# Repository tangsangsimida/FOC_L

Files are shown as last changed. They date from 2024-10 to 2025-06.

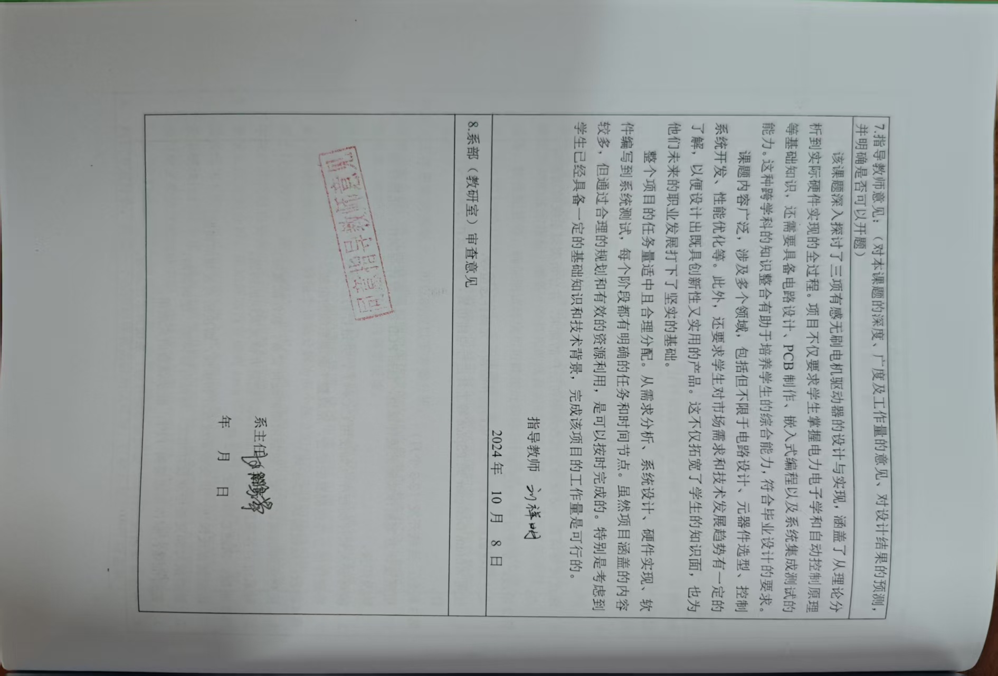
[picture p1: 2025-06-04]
paper/2203080517-汤红辉-智慧健康学院-三项有感无刷电机驱动器硬件设计/开题报告.jpg

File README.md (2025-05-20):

**目录结构概述**:  
该路径包含 6 个目录和 9 个文件，主要涉及 FOC（Field-Oriented Control，磁场定向控制）算法相关的项目、课程资料、代码库和文档。

---

### 目录结构详情

#### 目录 (6 个)
1. **参考项目**: 包含与 FOC 相关的参考项目或示例代码。
2. **CawFOC**: 一个 FOC 算法的实现项目或代码库。
3. **DengFOC**: 一个 FOC 算法的实现项目或代码库。
4. **odriver**: 与电机驱动相关的项目或工具。
5. **ts_foc_fw**: 与 FOC 固件（Firmware）相关的项目。
6. **Tsfoc_Soft_V0_1**: 一个 FOC 软件的早期版本（V0.1）。

#### 文件 (9 个)
1. **【手把手教学FOC算法】 课程例程包.zip**: 包含 FOC 算法的教学课程和示例代码的压缩包。
2. **bldc-master.zip**: 与 BLDC（无刷直流电机）相关的代码库或项目压缩包。
3. **eg2133_34对比.md**: 关于 eg2133 和 eg2134 芯片对比的 Markdown 文档。
4. **gitpush.sh**: 用于自动化 Git 推送操作的 Shell 脚本。
5. **LICENSE**: 项目的许可证文件，说明代码的使用权限和限制。
6. **README.md**: 项目的说明文档，包含项目简介、使用方法等信息。
7. **SCH_G431永磁双驱_2024-10-08.json**: 与永磁双驱电机相关的原理图设计文件（JSON 格式）。
8. **simple_focproject.zip**: 包含一个简单的 FOC 项目的压缩包。
9. **tree.txt**: 当前文件，记录了目录结构的树形图。

---

### 备注
- 该路径内容围绕 FOC 算法及其相关应用，包括电机控制、固件开发、课程资料等。
- 文件类型包括压缩包（`.zip`）、Markdown 文档（`.md`）、Shell 脚本（`.sh`）、JSON 文件等，表明项目内容多样化。

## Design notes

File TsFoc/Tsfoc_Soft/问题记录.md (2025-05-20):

# FOC开发过程中所遇到的关于软件和硬件上的坑

## 软件：

1. 结构体指针中包含结构体指针在申请内存的时候需要分别将所有结构体指针以及所包含的所有指针分别申请内存
2. stm32单片机的堆栈大小是通过cubeMX生成的时候自定义的，大量的结构体指针可能会导致堆区空间不足导致内存申请失败

## 硬件

1. 径向磁铁安装必须与编码器芯片对正，否则会出现精度丢失的情况，非常严重

# 当前为解决问题列表:

1. 低速正常，速度快一点之后就开始抖动，再快就死机了

   可能造成原因:

   角度传感器是模拟IIC速率可能不够

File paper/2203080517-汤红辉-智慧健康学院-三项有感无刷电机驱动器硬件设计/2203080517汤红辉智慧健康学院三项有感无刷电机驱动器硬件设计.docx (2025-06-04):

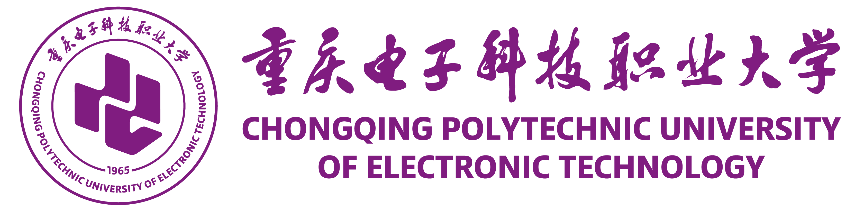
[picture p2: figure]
校徽与横式中英文标准字左右居中组合－重电紫（电子屏幕使用版）(1)

全日制学生毕业设计

任务书

学 院 智慧健康学院

专业班级 嵌入式技术应用

学生姓名 汤红辉 学号 2203080517

指导教师 刘祥明 王玺伟 职称 讲师 工程师

题 目 三项有感无刷电机驱动器硬件设计

2024年6月28日

毕业设计任务：

设计内容：1．掌握相关理论基础,深入学习和理解三项有感无刷电机（BLDC）的工作原理、控制策略及其应用场景。2．进行电机驱动电路的设计，包括但不限于功率电子元件的选择、电路拓扑结构的确定等。使用专业软件（如Altium Designer, PSpice等）进行电路仿真以验证设计的有效性。3. 基于设计方案制作实际的硬件原型，包括PCB板的设计与制作、元器件的焊接及调试。4.将硬件部分与控制算法结合，完成整个驱动系统的组装，并进行功能性和性能测试，确保其满足预期的技术指标。

设计指标：确保驱动器能够稳定驱动三项有感无刷电机，达到预定的速度和扭矩输出。实现对电机状态的实时监控与反馈调节，保证运行的安全性和稳定性。完成一套完整的硬件设计方案，包括电路图、PCB设计文件以及相关的技术文档。提交一份详尽的毕业设计论文，清晰阐述设计思路、实施步骤、实验结果及其分析。

设计任务要求：

1．具备扎实的电力电子学、自动控制原理等相关专业知识。2．能够熟练使用电路设计软件进行电路设计和仿真。3. 具有一定的动手能力，能够独立完成硬件的制作与调试工作。4. 在指导教师的帮助下，解决设计过程中遇到的各种问题，按时完成各阶段的任务。

主要参考文献：

[1]  顾伟康.一体化无刷直流电机控制研究和实现[D].东南大学,2015.
[2]  黄龙亮,胡鹏飞,陈玉洁,等.基于ARM的无刷直流电机容错控制系统研究[J].自动化应用,2024,65(12):103-104+108.DOI:10.19769/j.zdhy.2024.12.033.
[3]  王飞.BLDC驱动电路设计及应用[D].西安电子科技大学,2017.
[4]  谭加尼.基于STM32的无刷直流电机控制器研制[D].武汉工程大学,2020.DOI:10.27727/d.cnki.gwhxc.2020.000290.
[5]  敬心灵.基于STM32的无刷直流电机矢量控制系统研究[D].常州大学,2022.DOI:10.27739/d.cnki.gjsgy.2022.000412.
[6]  马鸿德.BLDC电机控制器的研究与设计[D].中国海洋大学,2015.
[7]  王聪.基于STM32的无刷直流电机控制系统研究[J].微处理机,2022,43(02):11-15.
[8]  赵国清,武涵.基于STM32的无感无刷直流电机控制系统设计[J].自动化应用,2024,65(05):142-148+152.DOI:10.19769/j.zdhy.2024.05.042.
[9]  方思鹏.无刷直流电机高性能驱动电路的设计与实现[D].电子科技大学,2023.DOI:10.27005/d.cnki.gdzku.2023.003895.
[10]  张平稳.高速无刷直流电机控制系统硬件电路设计[J].自动化应用,2019,(09):44-45+48.DOI:10.19769/j.zdhy.2019.09.017.

进度计划：

2024年9月 16 日至2024年10月19日：进行相关文献查找和阅读，了解三项有感无刷电机的工作原理及其驱动器设计的基本概念，并完成开题报告及开题答辩。

2024年10月20日至2024年12月21日：深入学习电机控制理论、电路设计基础以及相关电子元件的选择。开始进行初步的硬件设计工作，包括电路图绘制和元件选型。

2024年12月22日至2025年2月21日：完成详细的硬件设计方案，包括PCB设计、元器件采购等。着手制作原型并进行初步测试，确保各部分功能正常。

2025年2月22日至2025年3月21日：进行全面的系统集成和测试，优化驱动器性能。撰写毕业设计论文初稿，并进行查重。

2025年3月22日至2025年4月24日：进一步完善毕业设计论文，根据实验结果调整和优化设计。

2025年4月25日至2025年5月8日：准备答辩材料，完成毕业设计答辩。

任务起止日期： 2024 年 10 月 19 日至 2025 年 5 月 8 日

指导教师签字：

全日制学生毕业设计

开题报告

题 目 三项有感无刷电机驱动器硬件设计

学 院 智慧健康学院

专业班级 嵌入式2202

学生姓名 汤红辉 学号 2203080517

指导教师 刘祥明 王玺伟 职称 高级实验师

2024年 10月 8日

毕业设计（论文）开题报告

1.课题目的及意义，国内外研究现状分析

目的：

本项目旨在设计并实现一个用于三项有感无刷电机的高效、可靠的驱动器硬件。通过这一设计，期望能够优化电机控制性能，提高能效比，并为工业应用提供一种新的解决方案。

意义：

1. 提升电机运行效率和可靠性。
2. 推动电机控制技术的发展，特别是在高效节能领域。
3. 应对现代工业中对高性能电机驱动器的需求，促进相关产业的技术升级。

国内研究现状：

在中国，随着工业自动化水平的不断提高和对能源效率的关注增加，对于高性能电机驱动系统的需求日益增长。三项有感无刷电机（BLDC）因其高效能、长寿命以及良好的控制性能，在众多领域得到了广泛应用，如家用电器、电动车、工业自动化等。然而，相较于国际先进水平，国内在三项有感无刷电机驱动器的设计与制造方面仍存在一定的差距。虽然国内已有不少企业在进行三项有感无刷电机及其驱动器的研发和生产，但在高端应用领域，如航空航天、精密机床等，其电机控制精度和稳定性仍有待提高。当前国内市场上的电机驱动产品主要集中在中低端市场，而高端市场的份额则被国外品牌占据。这表明国内企业需要进一步提升技术水平以满足更高质量标准的要求。近年来，中国政府出台了一系列鼓励创新和技术升级的政策措施，旨在推动包括电机驱动在内的制造业向更高附加值方向转型。这些政策为电机驱动技术的发展提供了有力的支持。

国外研究现状：

在国外，尤其是欧美发达国家和地区，三项有感无刷电机驱动器的研究和应用已经达到了较高的水平，并广泛应用于多个高科技领域。国外研究机构和企业在三项有感无刷电机驱动器的技术创新方面取得了显著进展。例如，采用先进的控制算法（如矢量控制、直接转矩控制等）提高了电机的运行效率和动态响应速度；利用新材料（如碳化硅SiC功率器件）提升了驱动器的工作频率和能量转换效率。在高端制造、新能源汽车、医疗器械等领域，三项有感无刷电机驱动器的应用非常普遍。这些应用场景要求极高的可靠性、精确度以及适应复杂环境的能力，国外的产品往往能够更好地满足这些需求。为了降低开发成本并加快产品上市时间，许多国外制造商倾向于采用标准化和模块化设计理念。这种方法不仅有助于提高产品的兼容性和可维护性，还能促进整个行业的健康发展。

综上所述，尽管国内外在三项有感无刷电机驱动器的研究和发展方面均取得了一定的成绩，但总体来看，国外在技术创新、高端应用以及标准化设计等方面仍然领先于国内。因此，如何吸收借鉴国外先进技术经验的同时结合本国实际情况进行自主创新，是未来中国电机驱动行业面临的重要课题。通过持续的技术研发投入和人才培养，有望缩小与国际先进水平之间的差距，并在全球竞争中占据一席之地。

2.本课题的任务、重点内容、实现途径

课题任务：

设计并实现一款三项有感无刷电机驱动器，满足特定应用场景下的性能要求。完成从理论分析到实际硬件实现的全过程，包括电路设计、PCB制作、元件选型及系统集成测试。

重点内容：

在设计与开电机驱动时，需要重点关注以下几个方面：

1. 需求分析：明确驱动器的功能需求、性能指标以及用户需求。
2. 系统设计：包括电路设计、元器件选择、PCB布局等。
3. 数据处理与控制算法：开发适合的控制策略，保证电机高效稳定运行。

实现途径：

1. 使用Altium Designer或PSpice等工具进行电路设计与仿真
2. 进行详细的硬件原型设计与制作，并通过实验验证其性能。

硬件系统测试：对系统进行全面的测试，包括功能测试、性能测试和安全测试等，确保系统的稳定性和安全性。

3.课题可行性分析

三项有感无刷电机驱动器硬件设计项目的技术可行性主要基于以下几个方面：

1. 现有的技术基础：当前，电力电子技术和自动控制理论已经非常成熟，为本项目的实施提供了坚实的技术支持。例如，矢量控制和直接转矩控制等先进的电机控制算法已经被广泛应用于无刷直流电机的驱动系统中。此外，现代微控制器（MCU）和数字信号处理器（DSP）的发展也为电机控制系统的实现提供了强大的计算能力和丰富的接口资源。
2. 软件工具的支持：Altium Designer、PSpice等电路设计和仿真软件能够有效地辅助进行电路设计与验证。这些工具不仅简化了设计流程，还提高了设计的准确性和可靠性。通过这些软件工具的应用，可以对电路设计进行详细的仿真测试，提前发现并解决潜在的问题。
3. 元器件的选择：随着半导体制造工艺的进步，功率MOSFET、IGBT等高效能电子元件的成本不断下降，性能不断提升，这为三项有感无刷电机驱动器的设计提供了更多选择。同时，市场上也出现了许多专门为电机控制设计的专用集成电路（ASIC），这些都极大地促进了电机驱动器的小型化、高效化发展。
4. 成本效益分析：虽然高性能的电机驱动器在研发初期可能需要较高的投入，但考虑到其长期运行中的节能效果以及维护成本的降低，整体经济效益显著。特别是对于工业自动化领域，高效的电机驱动系统不仅能提高生产效率，还能大幅减少能源消耗，从而带来可观的经济回报。
5. 市场需求潜力：随着全球范围内对节能减排要求的不断提高，市场对高效能电机驱动器的需求日益增长。尤其是在新能源汽车、智能家居等领域，三项有感无刷电机驱动器的应用前景广阔。因此，开发一款性能优异的产品具有广阔的市场空间和良好的商业价值。

4.完成本课题所需的工作条件（如工具书、计算机、实验、调研等）及解决办法

学生宿舍管理系统的设计与实现课题所需的工作条件包括以下几个方面：

1. 工具书和文献：需要查阅与电力电子、自动控制理论、三项有感无刷电机及其驱动技术相关的专业书籍和技术文档。获取最新的研究成果和技术进展，以保证设计方案的先进性和科学性。

解决办法：利用学校图书馆或在线数据库查找并借阅相关领域的权威书籍和学术论文。参考官方文档和技术手册，以及所选用元器件的技术说明书。加入相关的技术论坛和社区，以便及时获取行业动态，并与其他研究者交流心得。

2. 计算机及软件环境：需要一台或多台配置较高的计算机用于电路设计、仿真、PCB制作以及后续的数据处理和分析工作。

解决办法：根据项目需求，选择适合的计算机配置，确保其能够满足高性能计算的要求。可以考虑使用学校的实验室资源或者自购高性能计算机。下载并安装所需的软件工具，确保所有工具均为最新版本，以获得最佳的功能支持和技术支持。对于一些昂贵的专业软件，可以通过教育许可的方式获取免费或低成本的使用权，许多软件厂商为学生提供特别优惠。

3. 实验条件：需要在一个配备齐全的实验室环境中进行硬件原型的制作和测试。这包括焊接设备、测量仪器（如示波器、万用表等）、电源供应器等。准备足够的测试数据，包括电机参数、运行状态记录等，以验证系统的正确性和稳定性。

解决办法：与学校实验室管理部门协商，争取获得实验室资源的使用权，特别是那些专门用于电子电路设计和测试的实验室。构建详细的测试计划，准备充分的测试数据和场景，确保每一个功能模块都能得到全面而严格的测试。

4. 调研：需要对现有的三项有感无刷电机驱动系统进行深入调研，了解其功能特点、优缺点以及用户反馈。收集目标应用领域的需求信息，明确最终用户的实际需求，为系统设计提供依据。

解决办法：通过问卷调查、访谈等方式直接从潜在用户那里收集需求信息。同时，也可以参考已有的市场研究报告和技术白皮书。参加行业会议、研讨会或展会，了解最新的产品趋势和技术发展动态。这不仅有助于获取第一手资料，还能建立有价值的行业联系。分析竞争对手的产品，找出它们的优势和不足之处，从而为自己的设计提供改进方向。

5.工作思路及方案分析

为了确保《三项有感无刷电机驱动器硬件设计》项目的顺利进行，以下是详细的工作思路及各阶段的方案分析：

1. 需求分析:明确项目的目标，包括提高电机控制精度、增强系统稳定性、优化能效等。通过问卷调查、访谈等方式收集来自潜在用户或相关领域的反馈信息，了解他们的具体需求。针对不同用户群体（如研发人员、维护人员和最终用户）的需求进行分析。研究市场上现有的同类产品，分析其功能特点、优缺点以及用户反馈，为本项目提供参考。整理调研结果，形成详细的需求文档，涵盖功能需求、性能需求、安全需求等方面，并明确优先级。在初步设计完成后，制作一个简易原型，进行初步测试以验证基本功能是否满足需求。
2. 系统设计:定义系统的整体架构，包括硬件部分（电路拓扑结构、元器件选型）、软件部分（控制算法的选择）以及人机交互界面的设计，考虑到电机驱动器的安全性要求，需加入必要的保护机制，如过流保护、温度监控等。编写详细的系统设计文档，包括ER图、流程图、电路原理图、PCB布局图等，确保设计的每个细节都经过充分考虑。使用Altium Designer、PSpice等工具进行电路仿真，验证设计方案的可行性和有效性。对于复杂的控制系统，可以利用MATLAB/Simulink进行系统级仿真。
3. 系统实现：根据设计方案制作实际的硬件原型，包括PCB设计、元器件采购及焊接。确保所有元件的质量符合标准，并按照设计图纸精确组装。如果涉及到嵌入式软件开发，则需编写相应的控制程序，并进行调试。选择合适的编程语言和开发环境（如C/C++、Keil、IAR等）。将硬件和软件部分结合起来进行全面的系统集成测试，确保各模块能够协同工作，达到预期的功能和性能指标。采用模块化设计方法，提高代码复用性和可维护性。每个功能模块独立开发和测试，最后集成到整个系统中。利用Eclipse等集成开发环境（IDE）提供的调试工具，方便进行代码调试，快速定位并解决问题。
4. 测试：包括测试范围、方法和标准，编写全面的测试用例，覆盖所有功能点和边界条件。按照预定的测试计划执行单元测试、集成测试和系统测试，记录并修复发现的问题。基于测试结果，对系统进行必要的性能优化，确保其满足预期的技术指标。准备一个模拟的或真实的测试环境，包括所需的硬件设备、软件配置等，确保测试环境尽可能接近实际应用场景。利用自动化测试工具（如LabVIEW, TestStand）来加速测试过程，提高测试效率和准确性。通过故意引入故障（如电源波动、信号干扰），测试系统的鲁棒性和自我恢复能力。

在以上工作思路的基础上，可以制定以下方案分析：

1. 需求方案分析：通过问卷调查和面对面访谈的方式收集来自潜在用户（如研发人员、维护人员）及领域专家的需求反馈。
2. 系统设计方案分析：使用Altium Designer或PSpice等专业软件进行电路设计与仿真，这些工具提供了直观的图形界面，使得电路设计和调试更加便捷。采用模块化设计理念，将整个系统分解为多个独立但相互关联的功能模块，便于后续的开发、测试和维护。根据性能要求选择合适的电子元件，考虑成本效益的同时也要保证系统的稳定性和可靠性。
3. 系统实现方案分析：虽然原始内容提到Java语言，但对于本项目而言，更适合选用C/C++或其他适用于嵌入式系统的编程语言进行控制程序的编写。采用模块化开发方式，提高代码复用性和可维护性。每个模块应具有清晰的接口定义和独立的功能实现。选择适合的集成开发环境（IDE），如Keil或IAR，它们提供了强大的调试工具，有助于快速定位和解决问题。
4. 测试方案分析：构建一个模拟的或真实的测试环境，包括必要的硬件设备和软件配置。确保所有组件均按照设计规格正确安装和配置。对系统的各个功能模块进行全面测试，包括但不限于电机启动/停止、速度控制、位置控制等功能。特别关注关键性能指标，如响应时间、精度等。基于测试结果对系统进行必要的调整和优化，确保其在各种工况下都能稳定运行，并达到预期的技术指标。

6.时间安排及工作进度

为了确保《三项有感无刷电机驱动器硬件设计》项目的顺利推进，以下是详细的时间安排和工作进度计划：

第1阶段：启动和需求分析（1-2周）

1. 收集关于三项有感无刷电机及其驱动系统的技术资料，进行初步的市场调研。
2. 通过问卷调查、访谈等方式收集潜在用户的需求，并分析类似系统的功能特点。

第2阶段：系统设计（1-2周）

1. 设计系统的总体架构，包括电路拓扑结构、元器件选型等。
2. 使用Altium Designer或PSpice等工具进行电路仿真，验证设计方案的可行性。

第3阶段：系统开发（2-3个月）

1. 根据设计方案制作实际的硬件原型，包括PCB板的设计与制作、元器件采购及焊接。
2. 编写嵌入式控制程序（如使用C/C++），并进行初步调试。
3. 将硬件部分与控制算法结合，完成整个驱动系统的组装。

第4阶段：系统测试（2-3周）

1. 搭建全面的测试环境，包括所需的硬件设备、软件配置等。
2. 对系统的各项功能进行全面测试，记录并修复发现的问题。

第5阶段：课题总结阶段（1-2周）

1. 根据测试反馈进一步完善系统设计和实现，解决所有发现的问题。
2. 继续撰写和完善毕业设计论文，确保内容详实、逻辑清晰。
3. 答辩准备：制作课题答辩 PPT，展示课题研究成果。
4. 准备答辩所需的材料，如课题总结报告、系统演示视频等。

7.指导教师意见：（对本课题的深度、广度及工作量的意见、对设计结果的预测，并明确是否可以开题）

该课题深入探讨了三项有感无刷电机驱动器的设计与实现，涵盖了从理论分析到实际硬件实现的全过程。项目不仅要求学生掌握电力电子学和自动控制原理等基础知识，还需要具备电路设计、PCB制作、嵌入式编程以及系统集成测试的能力。这种跨学科的知识整合有助于培养学生的综合能力，符合毕业设计的要求。

课题内容广泛，涉及多个领域，包括但不限于电路设计、元器件选型、控制系统开发、性能优化等。此外，还要求学生对市场需求和技术发展趋势有一定的了解，以便设计出既具创新性又实用的产品。这不仅拓宽了学生的知识面，也为他们未来的职业发展打下了坚实的基础。

整个项目的任务量适中且合理分配。从需求分析、系统设计、硬件实现、软件编写到系统测试，每个阶段都有明确的任务和时间节点。虽然项目涵盖的内容较多，但通过合理的规划和有效的资源利用，是可以按时完成的。特别是考虑到学生已经具备一定的基础知识和技术背景，完成该项目的工作量是可行的。

指导教师

2024年 10 月 8 日

8.系部（教研室）审查意见

系主任（签字）

年 月 日

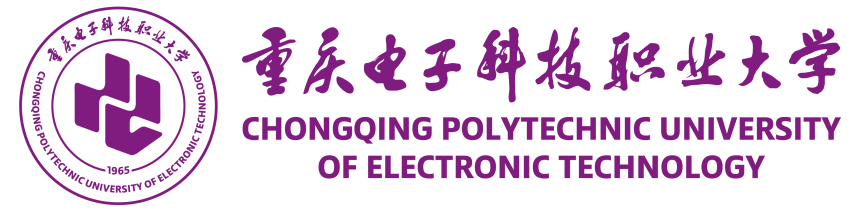
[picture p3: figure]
校徽与横式中英文标准字左右居中组合－重电紫（电子屏幕使用版）(1)

全日制本（专）科学生毕业设计

题 目 三项有感无刷电机驱动器硬件设计

学 院 智慧健康学院

专业班级 嵌入式2202班

学生姓名 汤红辉 学号 2203080517

指导教师 刘祥明 王玺伟 职称 讲师 工程师

评阅教师 贺晓辉 职称 副教授

2024年12 月 12日

宋体小3号，居中

毕业设计原创性声明

本人郑重声明：所呈交的毕业设计《三项有感无刷电机驱动器硬件设计》，是本人在指导教师指导下，在重庆电子科技职业大学学习期间进行的研究工作所取得的成果。据我所知，除文中已经标明引用的内容外，本论文不包含任何其他个人或集体已经发表或撰写过的研究成果。本人完全意识到本声明的法律结果由本人承担。

毕业设计作者：

2025年 5月 19日

毕业设计（论文）使用授权声明

本人完全了解重庆电子科技职业大学有关收集、保留和使用本人所送交的毕业设计（论文）的规定，即：学生在校期间毕业设计（论文）工作的知识产权单位属重庆电子科技职业大学。学校有权保留并向国家有关部门或机构送交毕业设计（论文）的复印件和电子版，允许论文被查阅和借阅，可以公布论文的全部或部分内容，可以采用影印、缩印或扫描等复制手段保存、汇编论文。保密的论文在解密后适用本声明。

论文涉密情况：

□ 不保密

□ 保密，保密期（起讫日期： ）

作者签名： | 指导教师签名：
2025年 5月 19日 | 2025年 5月 19日

摘 要

无刷直流电机（Brushless DC Motor, BLDCM）是一种寿命长、可靠性高且易于维护的机电一体化产品[1]。无刷直流电机运行可靠、功率密度高、寿命长、效率高，其在结构上去除了电刷和换向器，减少了电机的维护费用和因换向器而引起的电磁干扰[2]。无刷直流电机被认为是 21 世纪最具有发展潜力和应用前景的电机[3]。无刷直流电机以电子换相来代替机械换相，有效解决了传统有刷直流电机的不足[4]。近年来，全球智能化制造和发展成为主要趋势之一，无刷直流电机的价值被逐渐认知，随着高效无刷直流电机技术的不断发展，无刷直流电机的成本呈下降趋势，无刷直流电机被广泛应用在智能化相关产品中[5]。

无刷直流电机（BLDC电机）以其卓越的效能、长久的使用寿命和高度的可靠性，在工业自动化、消费电子、医疗设备、汽车工程以及航空航天等多个领域获得了广泛应用。随着现代科技日新月异的发展，对电机驱动系统的性能要求日益提升，尤其在效率、控制精度以及响应速度方面设定了更高的标准。这促使BLDC电机不断演进，以满足各行业对高性能驱动解决方案的需求。传统的有刷电机由于机械磨损问题，导致其使用寿命有限并且维护成本较高，而BLDC电机通过采用电子换向技术有效地解决了这些问题，因此成为现代高性能应用中的理想选择。传统的有刷直流电机的应用包括摩托车玩具，家用电器和计算机外围设备。汽车制造商把直流电机应用于电动车窗，座位和其他内饰设计，主要是因为它们的成本低，控制简单[6]。

为进一步挖掘无刷直流电机的应用潜力，通过对其结构及工作原理的研究，设计一种基于STM32F407的无刷直流电机控制系统[7]。本研究旨在结合STM32F407VET6微控制器、EG2133驱动芯片和AS5600位置传感器的优势，设计一款高性能的三相有感无刷电机驱动器。通过优化硬件设计和软件算法，提高驱动器的效率、可靠性和控制精度，以满足日益增长的高性能电机驱动需求。具体而言，我们将深入研究如何利用STM32F407VET6的高级处理能力来实现复杂的控制算法，同时通过EG2133驱动芯片确保功率输出的稳定性和安全性，并通过AS5600位置传感器提供精确的位置反馈，进一步提升系统性能。此外，本研究还将探讨如何降低成本、简化设计复杂度，使所设计的驱动器更易于在实际应用中推广使用。通过本研究，我们希望能够为行业提供一种更加经济、高效且可靠的解决方案，从而促进BLDC电机驱动技术的进一步普及和发展。

关键词：STM32；BLDC；EG2133；AS5600；PCB。

Summary

Brushless DC motors (BLDC motors), known for their longevity, reliability, and ease of maintenance, represent a sophisticated integration of mechanical and electrical engineering. These motors offer dependable operation, high power density, extended lifespan, and superior efficiency. By eliminating brushes and commutators from their design, BLDC motors reduce maintenance costs and mitigate electromagnetic interference caused by the commutator. Recognized as one of the most promising types of motors with significant potential for development and application in the 21st century, BLDC motors substitute electronic commutation for mechanical commutation, effectively addressing the limitations of traditional brushed DC motors. In recent years, with the global trend towards intelligent manufacturing, the value of efficient BLDC motors has been increasingly recognized. As technology advances, the cost of these motors is decreasing, making them widely used in intelligent products.

The BLDC motor, characterized by its outstanding performance, long service life, and high reliability, has found widespread application across various fields such as industrial automation, consumer electronics, medical devices, automotive engineering, and aerospace. The rapid advancement of modern technology has led to higher demands on the performance of motor drive systems, especially in terms of efficiency, control accuracy, and response speed. This drives continuous evolution in BLDC motors to meet the demand for high-performance drive solutions across different industries. Traditional brushed motors suffer from limited lifespan and high maintenance costs due to mechanical wear, whereas BLDC motors solve these issues effectively through electronic commutation, making them an ideal choice for modern high-performance applications. Traditional applications of brushed DC motors include motorcycle toys, household appliances, and computer peripherals, while automotive manufacturers use DC motors in electric windows, seats, and other interior designs mainly for their low cost and simple control.

To further explore the application potential of BLDC motors, this study focuses on designing a BLDC motor control system based on the STM32F407 by investigating the motor's structure and operational principles. Aimed at leveraging the advantages of the STM32F407VET6 microcontroller, EG2133 driver chip, and AS5600 position sensor, this research aims to design a high-performance three-phase sensor-equipped BLDC motor driver. Through optimizing hardware design and software algorithms, the goal is to enhance the efficiency, reliability, and control accuracy of the driver to meet the growing demand for high-performance motor drives. Specifically, we will delve into utilizing the advanced processing capabilities of the STM32F407VET6 to implement complex control algorithms, ensure stable and safe power output with the EG2133 driver chip, and provide precise position feedback through the AS5600 position sensor to improve system performance. Additionally, this study will examine ways to reduce costs and simplify design complexity, facilitating easier adoption of the designed driver in practical applications. Through this research, we aspire to offer a more economical, efficient, and reliable solution to promote the further dissemination and development of BLDC motor drive technology.

Keywords: STM32; BLDC; EG2133; AS5600; PCB.

目 录

# 1. 系统总体设计

## 1.1 设计需求分析

本研究旨在开发一款高性能的三相有感无刷电机驱动器，为此设定了以下关键指标：

### 1.1.1 性能指标设定

确保电机在各种工作条件下均能高效运行，以减少能量损耗，提高能源利用率。

实现对位置和速度的精准控制，满足工业应用中对高精度的要求，保障操作的一致性和准确性。

具备迅速适应动态负载变化的能力，增强系统的灵活性和即时响应能力，以应对多变的工作环境。

通过采用耐用组件并优化电路设计，确保系统能够长期稳定运行，降低故障率和维护成本。

### 1.1.2 功能要求细化

为达到上述性能目标，具体功能要求如下：

支持多种通信协议（UART、SPI、I2C、CAN、USB），以增强与外部设备的数据交互能力。

实现过流和过压保护机制，确保系统在遇到异常工况时的安全性。

配备实时温度监控功能，有效预防因过热引发的故障，保障设备稳定运行。

通过开发板上的显示屏，提供直观的用户界面，搭配上位机，便于参数配置和状态监控。

## 1.2 系统架构概述

本研究设计的三相有感无刷电机驱动器系统由多个关键模块组成，每个模块都承担着特定的功能，共同确保系统的高效运行和精确控制。

### 1.2.1 系统组成模块介绍

  1.2.1.1 核心控制单元

基于STM32F407VET6微控制器。该单元是整个系统的核心，负责执行复杂的控制算法，处理来自位置检测电路的位置反馈信息，并生成相应的PWM信号来控制功率驱动电路。此外，它还管理与外部设备的数据通信，支持多种通信协议（UART、SPI、I2C、CAN、USB），以实现灵活的数据交互。

  1.2.1.2 功率驱动电路

采用了EG2133驱动芯片及其外围电路。此部分的主要功能是接收来自核心控制单元的PWM信号，通过控制MOSFET开关来驱动BLDC电机，确保电机能够根据控制指令准确运转。同时，EG2133还提供了过流保护等安全机制，保障系统的稳定性和安全性。

  1.2.1.3 位置检测电路

使用AS5600位置传感器。这个模块提供精确的转子位置反馈信息给核心控制单元，使得控制系统可以根据实时的位置数据调整电机的转速和方向，从而实现精准的速度和位置控制。

  1.2.1.4 辅助电路

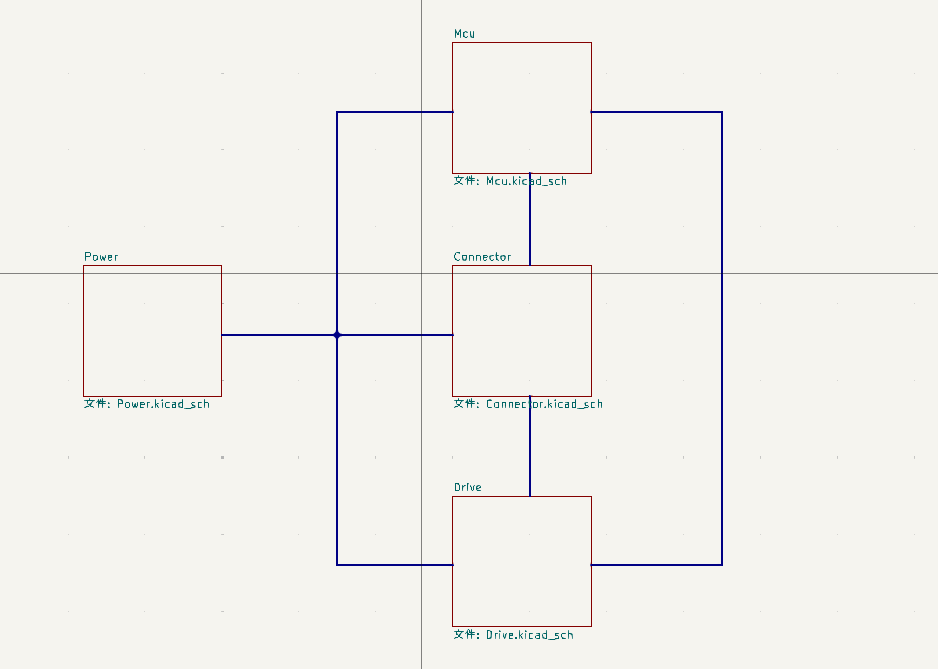
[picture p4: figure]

包括电源管理、过流过压保护以及温度监控等电路。这些电路虽然不是直接参与电机的驱动，但它们对于维持系统的正常运行至关重要。例如，电源管理电路确保了各模块得到稳定的供电；过流过压保护机制防止系统在异常情况下受到损害；而温度监控电路则用于监测系统工作温度，避免因过热导致的故障。

图1-1 系统结构

### 1.2.2 各模块间的数据交互

为了实现高效的协同工作，各模块之间需要进行紧密的数据交互：

核心控制单元通过SPI或I2C接口从位置检测电路获取转子位置信息，并据此计算出适当的控制策略，然后将PWM信号发送至功率驱动电路，实现对电机的精确控制。

辅助电路提供的状态信息（如电压、电流、温度）被实时传输给核心控制单元。例如，当检测到过流或过压情况时，核心控制单元会立即采取措施，比如降低输出功率或切断电源，以保护系统免受损坏。

在通信方面，核心控制单元不仅负责内部模块间的协调，还需与外部设备进行数据交换。这可以通过UART、USB、CAN等接口实现，允许用户配置参数、监控状态或者与其他控制系统集成。

## 1.3 关键技术选择依据

为了确保所设计的三相有感无刷电机驱动器具备高性能、高可靠性和良好的经济性，本研究在关键技术组件的选择上进行了深入分析和考量。以下是针对核心控制单元、功率驱动电路以及位置检测电路的关键技术选择依据。

### 1.3.1 TM32F407VET6选型考量

STM32F407VET6微控制器采用ARM Cortex-M4核心，具备多项特性，使其成为优选方案：

Cortex-M4内核支持浮点运算单元(FPU)，能够高效执行复杂的数学运算和实时控制算法，这对于BLDC电机的精确控制至关重要。

包括多个定时器、ADC（模数转换器）、DAC（数模转换器）、SPI/I2C/UART等通信接口，满足了系统内部与外部设备的数据交互需求。

适合长时间运行的应用场景，有助于提升系统的整体能效比。

拥有广泛的社区支持和成熟的开发工具链，便于快速原型设计和调试。

### 1.3.2 EG2133驱动方案分析

EG2133是一款专为无刷直流电机设计的专用驱动芯片，其选用理由如下：

集成了必要的保护功能（如过流保护），减少了外围电路的设计复杂度和成本。

优化的栅极驱动设计可以有效地减少开关损耗，提高整体效率。

内置的安全机制能够在异常情况下自动断电，防止损坏，增加了系统的鲁棒性。

提供了详细的参考设计和应用指南，简化了开发流程，缩短了产品上市时间。

### 1.3.3 AS5600传感器选择理由

AS5600磁性旋转编码器作为位置检测传感器的选择，主要基于以下几个方面：

能够提供准确的角度位置反馈，分辨率高达12位，适用于需要精密控制的应用。

通过I2C或SPI接口与微控制器连接，配置简便，易于集成到现有的控制系统中。

采用非接触式磁感应技术，不受灰尘、油污等环境因素的影响，适合工业环境下的长期稳定工作。

在保证性能的同时降低了能耗，有利于延长电池供电设备的工作时间或减少散热需求。

# 2. 核心控制单元硬件设计

## 2.1 STM32F407VET6最小系统设计

本项目选用STM32F407作为核心控制单元，它能够达到高达168 MHz的运行频率，并配备了多种外设接口，为控制系统的设计提供了坚实的硬件基础[8]。

在最小系统设计中，一般将BOOT0引脚接地，而BOOT1引脚的状态（接地或接高）则根据实际需求来定，以便实现从主闪存启动。

此外，对于未使用的输入引脚，建议通过上拉或下拉电阻确保它们处于确定状态，避免因浮空而导致的系统不稳定性。

### 2.1.1 电源电路设计

控制器的电源是整个系统稳定性的关键，该电路需提供稳定的3.3V电压，以满足微控制器内核（VDDA）和I/O端口（VDD）的需求，同时也考虑到可能需要的5V供电给外围设备。在选择电源解决方案时，使用低噪声线性稳压器ASM1117用于3.3V转换，高效的开关电源模块TPS5430从12V降至5V，以确保为整个系统提供平滑的电源。

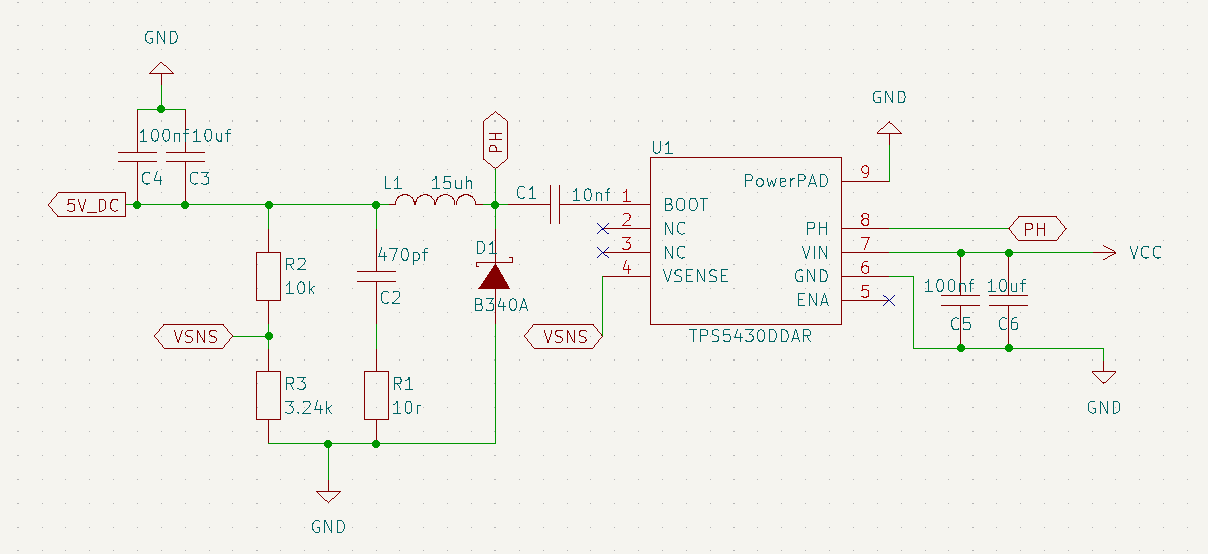
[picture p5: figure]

图2-1 5V电源

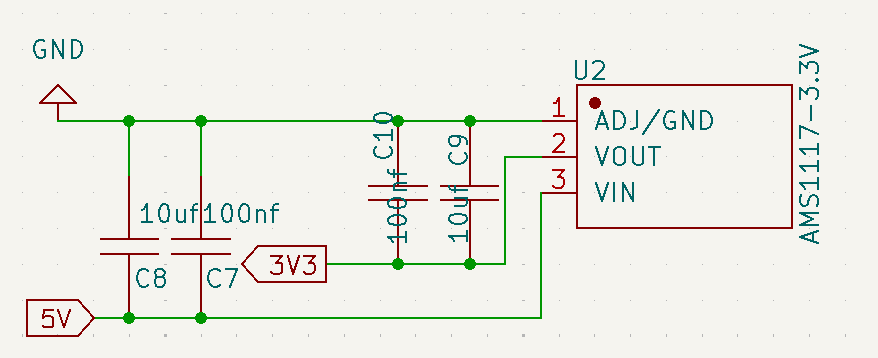
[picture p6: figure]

图2-2 3.3V电源

### 2.1.2 复位电路设计

复位电路的设计对于保证微控制器能够正确启动和恢复正常操作至关重要。一个良好的复位电路应当能够在电源上电时自动产生复位信号，并且在检测到异常情况（如电压跌落）时也能触发复位。此外，还可以加入手动复位按钮，以便于开发调试阶段使用。复位电路通常由电阻、电容及复位芯片组成，确保复位信号的稳定性与可靠性。

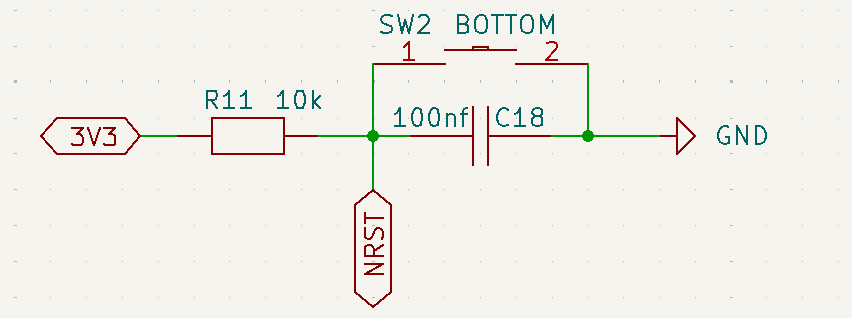
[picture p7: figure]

STM32F407VET6 具有一个NRST引脚用于复位。通常需要在此引脚上连接一个按键和一个上拉电阻（约10kΩ），以便手动复位。

图2-3 复位电路

### 2.1.3 时钟电路设计

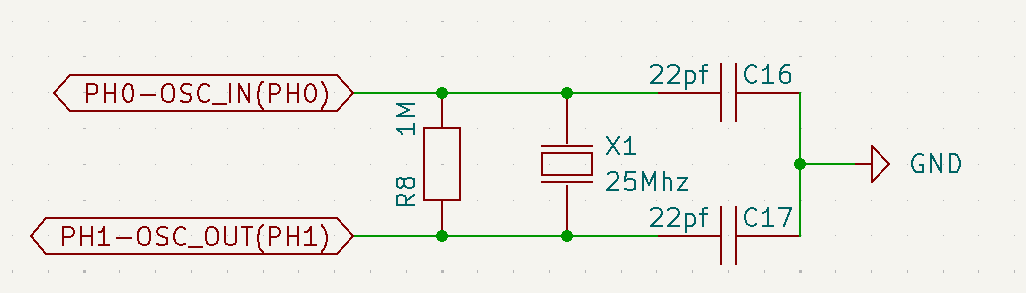
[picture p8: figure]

STM32F407VET6支持诸多时钟源选项，。为达到最佳性能表现，本设计选用外部8MHz晶振配合内部锁相环(PLL)技术来生成所需的系统时钟频率。时钟电路的设计需特别注意晶振的选择与布局，尽量减少信号干扰，同时也要考虑负载电容的匹配问题，以保证时钟信号的质量和稳定性。

图2-4 外部高速晶振

## 2.2 输入输出接口设计

在核心控制单元的设计中，输入输出（I/O）接口是实现与外部设备进行数据交换的关键部分。通过合理的I/O接口设计，可以提升系统的扩展性、兼容性和交互性能。本节将详细介绍通信接口设计和控制信号输出接口的设计思路与实现方法。

### 2.2.1 通信接口设计

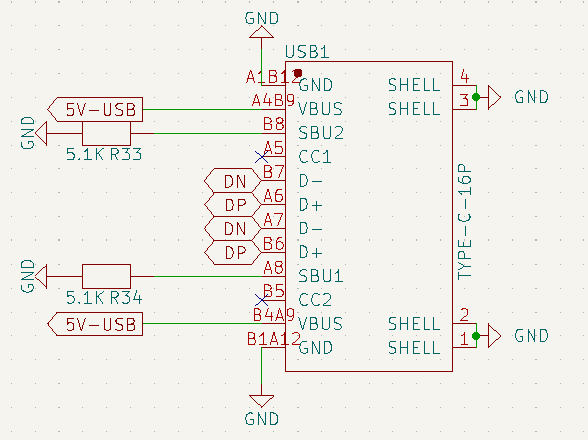
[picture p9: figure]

为了满足不同应用场景下的数据交互需求，STM32F407VET6微控制器支持多种通信协议，包括UART、SPI、I2C、CAN以及USB等。这些接口不仅为系统内部模块间的数据传输提供了便利，也使得与其他外部设备的连接更加灵活多样。

图2-5 USB接口

### 2.2.2 控制信号输出接口

除了通信接口之外，控制信号输出接口也是核心控制单元的关键部分。此接口主要用于向功率驱动电路发送PWM（脉宽调制）信号，实现对BLDC电机速度和方向的精确控制。此外，通过GPIO（通用输入输出）端口还可以输出其他类型的控制信号，例如使能信号和故障指示信号。设计时应重视信号完整性，采取适当的滤波和隔离措施以减少干扰，并注重接口保护设计，避免因过压或过流造成的损害。精心设计的控制信号输出接口能够大幅提升系统的稳定性和响应速度。

# 3. 驱动电路硬件设计

## 3.1 EG2133驱动芯片介绍

EG2133是一款专为无刷直流电机（BLDC）设计的专用驱动芯片，它集成了多种保护功能，例如过流保护、欠压锁定等功能，可以显著提高系统的安全性和稳定性。该芯片具有高集成度和高效性能的特点，其优化的栅极驱动设计可以显著减少开关损耗，提高整体效率。

## 3.2 功率驱动电路设计

### 3.2.1 MOSFET选型与参数计算

功率驱动电路的关键组件是MOSFET（金属氧化物半导体场效应晶体管），其选型直接关系到整个驱动系统的性能表现。在选型过程中，需考虑MOSFET的最大漏源电压（Vds）、最大连续漏电流（Id）、导通电阻（Rds(on)）以及开关速度等关键参数。为了确保系统能够在不同的工作条件下稳定运行，还需要进行热分析以确定所需的散热措施。根据具体的负载要求，通过计算所需的最大电流和电压来选定合适的MOSFET型号，并进行相应的参数配置。

### 3.2.2 驱动电路原理图设计

驱动电路的设计基于EG2133驱动芯片，结合所选MOSFET的具体参数进行布局。首先，根据EG2133的数据手册设计外围电路，包括电源滤波电容的选择、栅极电阻的设置等，以确保信号传输的稳定性和可靠性。其次，绘制完整的驱动电路原理图，明确各元件之间的连接关系及电气特性。特别地，对于MOSFET的栅极驱动部分，需注意防止自激振荡现象的发生，通常可以通过添加适当的阻尼电阻或使用专门的栅极驱动IC来解决这一问题。

自举电路是一种在高边 NMOS 管栅极驱动中常见的电路结构。该电路以以自 举电容为核心，通过电荷转移的方式，将充至一定电压的自举电容下极板接至高边 NMOS 管源极而上极板接至高边 NMOS 管的栅极，使高边 NMOS 管能够开启[9]。

# 4. 位置检测电路设计

## 4.1 AS5600传感器工作原理

AS5600是一款采用霍尔效应原理设计的磁性旋转编码器，专门用于精确测量旋转角度。它通过检测磁场变化来确定转子的位置，并能提供最高达12位分辨率的角度信息。该传感器兼容I²C和SPI接口，便于与微控制器（如STM32F407VET6）进行高效的数据交换，简化了系统集成步骤。此外，AS5600还配备了低功耗模式，可以在不牺牲性能的前提下大幅延长电池供电设备的操作时间。因此，无论是在工业自动化、消费电子领域，还是其他需要精确角度测量的应用场景中，AS5600都展示了出色的灵活性和可靠性，成为提升产品性能并优化能耗的理想组件。

## 4.2 位置检测电路设计

### 4.2.1 传感器接口电路设计

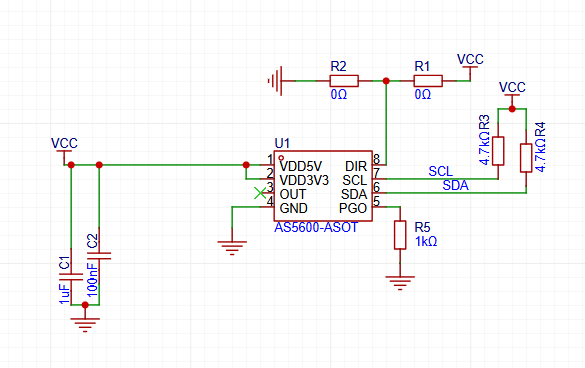
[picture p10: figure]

为了确保AS5600能够准确地向STM32F407VET6传输位置信息，需要设计一个合适的接口电路。首先，根据AS5600的数据手册配置I2C或SPI接口，包括选择适当的上拉电阻值以保证信号完整性。其次，考虑到电磁干扰可能对信号传输造成的影响，应在设计中加入滤波电容，特别是在电源引脚附近添加去耦电容以稳定电压。最后，还需注意布线时尽量缩短信号线长度，减少外界噪声干扰，确保数据传输的准确性。

图4-1 AS5600电路

### 4.2.2 数据处理与传输电路设计

对于控制系统来说，理解控制对象的特性至关重要。这些特性通常需要通过信号处理电路和传感器来采集，并在处理后将数据传输到核心控制芯片。最终，利用相应的控制算法实现特定的控制策略[10]。

在利用AS5600提供的高精度位置信息时，STM32F407VET6通过一套精心设计的数据处理与传输方案来实现高效的电机控制。AS5600直接通过I²C或SPI接口提供数字信号，无需经过ADC转换，确保了数据的高保真度和快速获取。

为了加速数据传输并减轻CPU负担，采用了DMA（直接存储器访问）技术，使数据能够迅速从AS5600传输至STM32的内存中，从而实现了数据流的高效管理，同时释放了CPU资源用于更复杂的任务处理。

接下来，通过优化算法实时计算电机的实际转速和位置误差。根据这些精确的计算数据，系统动态调节PWM信号的占空比，从而实现精准的速度和位置控制。此闭环反馈机制确保了电机运行的高度稳定性和快速响应能力。

在整个操作过程中，系统持续监控关键参数，如电流、温度等，以实时检测异常情况。一旦发现任何潜在问题，系统立即采取保护措施，例如切断电源，防止电机及其他组件受损，确保系统的安全可靠运行。

# 5. 其他辅助电路设计

## 5.1 电源管理电路设计

在高性能三相有感无刷电机驱动器的设计中，除了核心控制单元和功率驱动电路之外，辅助电路同样扮演着至关重要的角色。这些辅助电路涵盖了电源管理、过流过压保护以及温度监控等功能模块。它们相互配合，不仅保障了系统的稳定运行，还显著增强了系统的安全性。通过精密的电源管理来维持电压和电流的稳定性，利用过流过压保护机制防止电气故障对系统造成损害，并借助温度监控实时跟踪系统热状态以避免过热风险，这些精心设计的辅助功能模块是保障整个驱动系统高效、可靠运作的关键所在。

## 5.2 保护电路设计

### 5.2.1 过流保护机制

在确保系统各组件稳定运行的过程中，电源管理电路起着基础性的作用。它不仅需要为STM32F407VET6微控制器、EG2133驱动芯片及AS5600位置传感器等提供稳定的电压供给，还需充分考虑各模块对电源的特定需求差异。因此，在设计电源管理电路时，选取适合的稳压器非常关键。针对低噪声需求高的组件，如传感器和微控制器，推荐使用低压差线性稳压器（LDO）；对于功率需求较高的部分，应选择效率更高的开关模式电源（SMPS）。这样既能满足各个组件的电压和电流要求，又能优化系统的电磁兼容性（EMC）表现。

为了进一步提升系统的可靠性，实施电源冗余设计是至关重要的。通过建立主电源和备用电源之间的自动切换机制，可以在主电源失效时立即启用备用电源，确保系统持续稳定运行，避免因电源故障引起的中断或硬件损坏。

在电源管理中加入过流保护机制同样重要。过流保护能够实时监测电路中的电流水平，并在检测到异常高电流时立即采取措施，比如切断电源或触发报警信号，以避免电路损坏或潜在的安全风险。这种多层次的设计策略，不仅保证了各组件的正常工作，还大幅提升了整个系统的安全性与稳定性。

### 5.2.2 过压保护措施

选择一个低阻值且功率耗散能力足够的精密电阻串联在电机回路中。该电阻用于监测通过电机的实际电流大小。其阻值需根据预期的最大电流来确定，同时确保不会对电路的整体效率产生显著影响。

当电流超过预设的安全阈值时，比较器能够迅速检测到这一变化，并立即向STM32F407VET6微控制器发送信号。基于此信号，微控制器可以执行相应的保护动作，如降低PWM占空比或切断电源供应，从而避免系统因过流而受损。

此外，为了进一步提升系统的鲁棒性，在设计时还应考虑以下几个方面：

在电流检测点附近添加适当的滤波电容，以减少瞬态电流波动对检测结果的影响，确保比较器接收到的信号更加稳定可靠。

除了硬件上的保护措施外，还可以在软件中实现额外的监控逻辑。如定期检查电流水平并在发现异常时记录日志或触发警报，以便后续分析和故障排查。

## 5.3 温度监控与保护电路设计

由于BLDC电机及其驱动器在运行过程中会产生大量热量，因此必须配备有效的温度监控与保护机制。首先，在关键发热区域安装NTC（负温度系数）热敏电阻作为温度检测元件，实时监控系统的温度变化。然后，利用ADC将模拟温度信号转换为数字信号，并传输给STM32F407VET6进行处理分析。如果检测到温度超出安全范围，应立即发出警报并启动散热风扇进行降温。

# 6. 功能与性能验证

为了验证驱动板硬件电路设计是否正确。控制算法（FOC）是否能正常运行。测试驱动器在不同负载和转速下的稳定性与效率。确保安全保护机制有效（过流、欠压、过温等）。评估驱动器对电机响应的准确性与实时性。

## 6.1 实验设备

本次实验所需设备主要包括：三相无刷电机、自主研发的三相无刷电机驱动板、可调直流电源或匹配电压的电池组、示波器用于观测PWM波形及霍尔信号、万用表用于测量电压和电流、负载装置用于模拟实际工况、编码器模块用于反馈转子位置、主控单元运行控制程序，以及散热片和风扇等辅助散热装置，确保系统在测试过程中稳定运行。

## 6.2 实验步骤与测试内容

### 6.2.1 通电前准备与初步检查

确认电源、驱动板、电机、控制器之间的接线正确可靠，接地良好。在未上电状态下检测各供电模块是否存在短路或反接现象。确保控制程序已下载至主控芯片，并能正常启动。

### 6.2.2 空载功能测试

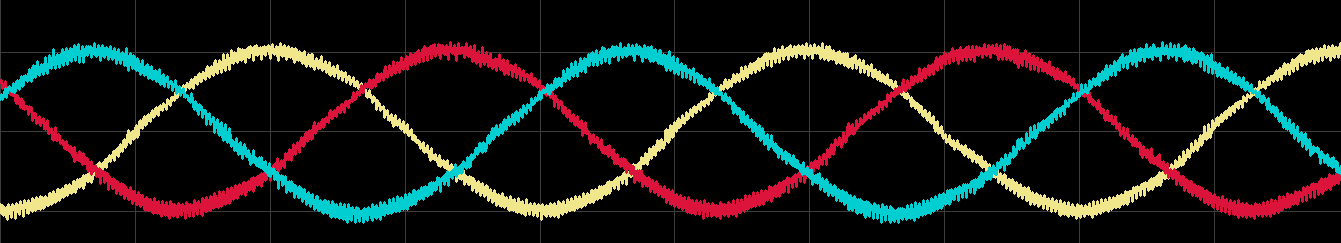
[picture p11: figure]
PEControllerを使用した昇圧コンバータ付き三相グリッド・タイ・インバータ｜アプリケーション例｜タラズ・テクノロジーズ

PWM信号输出测试是空载测试的核心部分之一，旨在验证PWM信号生成模块的功能。利用示波器观察三相PWM输出波形，确保PWM频率适合所使用的电机类型。调整占空比，观察其变化是否符合预期。检查是否存在适当的死区时间，防止上下桥臂同时导通造成短路。三相PWM应保持对称，避免某一相的异常导致电机不平衡运转。

图6-1 示波器截图

### 6.2.3 闭环控制测试

闭环控制测试采用位置闭环的模式进行测试，位置闭环控制测试是为了验证驱动器能否根据给定的位置指令精确地控制电机转子到达指定位置。这种类型的测试对于需要精确定位的应用（如机器人关节、精密机床等）至关重要。

在测试过程中，通过串口调试软件向上位机发送目标角度指令，驱动器接收指令后解析并执行相应的控制动作，驱动电机快速响应并定位至设定位置。实验重点考察系统的定位精度、响应速度以及运行稳定性。

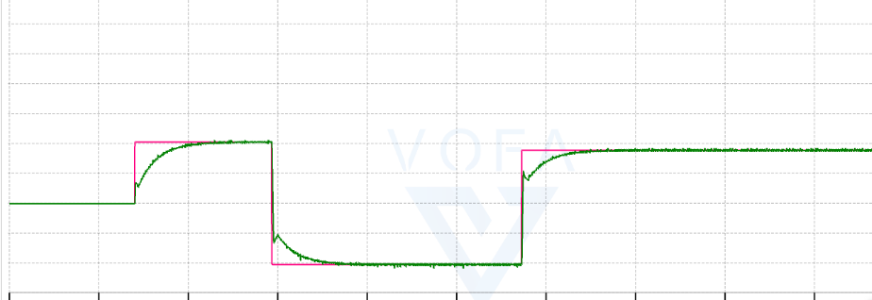
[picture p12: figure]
电机控制（三）--- vofa+波形打印-CSDN博客

测试结果表明，驱动器能够准确解析上位机发送的角度指令，电机在接收到指令后能够迅速启动并稳定运行至目标位置，展现出良好的动态响应能力和控制精度，满足基本的高精度定位需求。

图6-2 设定角度与实际角度波形

## 6.3 实验总结

本次三相无刷电机驱动器的验证实验，围绕硬件功能、控制逻辑及系统稳定性等方面展开。通过空载与带载测试，验证了驱动板能够正常输出PWM信号并实现电机平稳运行；示波器观测结果显示换向逻辑正确，死区设置合理，有效防止上下桥臂直通。闭环控制测试中，系统具备良好的速度响应能力和稳态精度，满足基本控制需求。同时，过流、欠压等保护功能也进行了模拟测试，初步验证其可靠性。整体来看，该驱动器在实验环境下表现稳定，达到了预期设计目标，为后续优化和实际应用奠定了基础。

# 7. 参考文献

[1] 顾伟康.一体化无刷直流电机控制研究和实现[D].东南大学,2015.
[2] 黄龙亮,胡鹏飞,陈玉洁,等.基于ARM的无刷直流电机容错控制系统研究[J].自动化应用,2024,65(12):103-104+108.DOI:10.19769/j.zdhy.2024.12.033.
[3] 王飞.BLDC驱动电路设计及应用[D].西安电子科技大学,2017.
[4] 谭加尼.基于STM32的无刷直流电机控制器研制[D].武汉工程大学,2020.DOI:10.27727/d.cnki.gwhxc.2020.000290.
[5] 敬心灵.基于STM32的无刷直流电机矢量控制系统研究[D].常州大学,2022.DOI:10.27739/d.cnki.gjsgy.2022.000412.
[6] 马鸿德.BLDC电机控制器的研究与设计[D].中国海洋大学,2015.
[7] 王聪.基于STM32的无刷直流电机控制系统研究[J].微处理机,2022,43(02):11-15.
[8] 赵国清,武涵.基于STM32的无感无刷直流电机控制系统设计[J].自动化应用,2024,65(05):142-148+152.DOI:10.19769/j.zdhy.2024.05.042.
[9] 方思鹏.无刷直流电机高性能驱动电路的设计与实现[D].电子科技大学,2023.DOI:10.27005/d.cnki.gdzku.2023.003895.
[10] 张平稳.高速无刷直流电机控制系统硬件电路设计[J].自动化应用,2019,(09):44-45+48.DOI:10.19769/j.zdhy.2019.09.017.

# 8. 致谢

首先，我们要感谢实验室为我们提供了一个卓越的学习环境，这为我们的学习和实验奠定了坚实的基础。

特别需要感谢的是我的指导老师，您的深刻见解、宝贵建议以及对科研工作的激情极大地鼓舞了我们，帮助我们克服了诸多挑战。您不仅在学术上给予了细致入微的指导，还在项目的各个关键节点提供了至关重要的支持与鼓励。

同时，我们也想表达对重庆电子科技职业大学的感激之情，感谢学校提供的优良科研条件和资源支持。让我能够全身心投入到这项工作中直至完成。

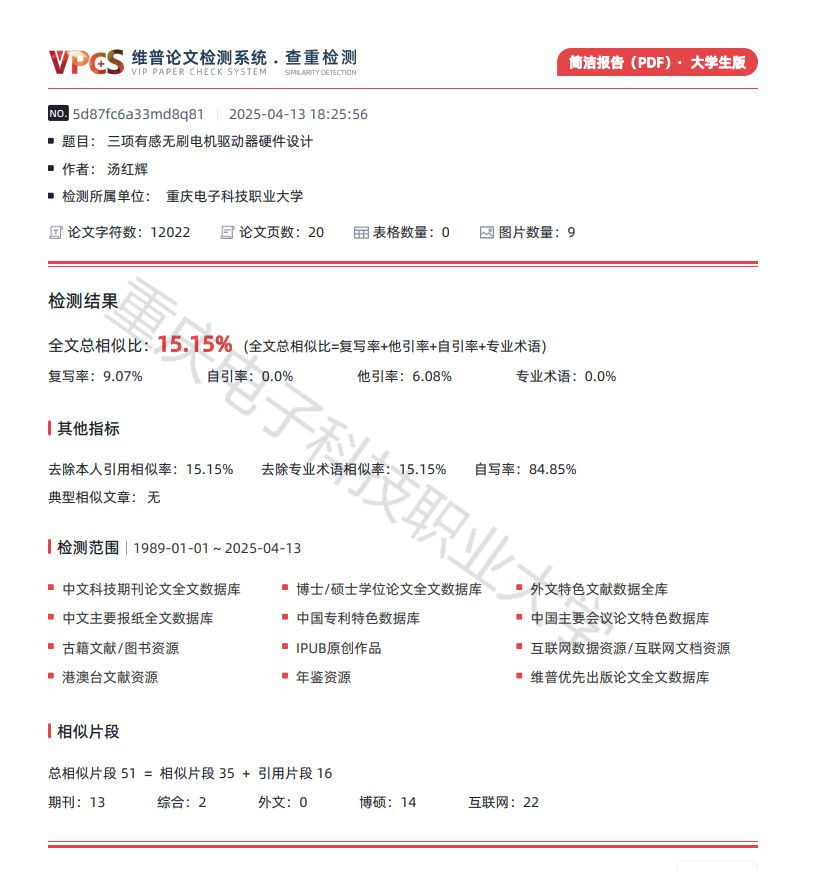
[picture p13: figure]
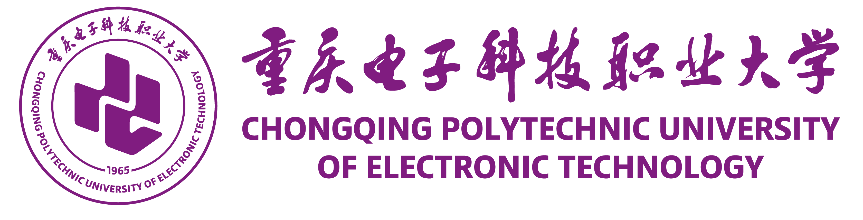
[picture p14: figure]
校徽与横式中英文标准字左右居中组合－重电紫（电子屏幕使用版）(1)

全日制学生毕业设计

成绩评定书

题 目 三项有感无刷电机驱动器硬件设计

学 院 智慧健康学院

专业班级 嵌入式技术应用2202

学生姓名 汤红辉 学号 2203080517

指导教师 刘祥明/王玺伟 职称 讲师/工程师

2025年5月18日

毕业设计（论文）成绩评定总表

姓 名 | 汤红辉 | 学号 | | 2203080517 | | 专业 | 嵌入式技术应用
题 目 | 三项有感无刷电机驱动器硬件设计
指导教师 | 刘祥明/王玺伟 | | | | 职 称 | | 讲师/工程师
学 生 总 成 绩 | 设计成绩 (百分制) | | 指导教师评分：85 评阅教师评分：85 答辩评分：80
| 折合比例 | | 指导教师评分(40％)；评阅教师评分(30％)；答辩评分(30％)
| 实得成绩 | | 总分：_____83.5________；
| 总 评 等 级 | | 毕业设计总评等级（五级制）： 学院分管领导(签字)： 学院(签章) 年 月 日

毕业设计（论文）指导教师成绩评定表

姓 名 | 汤红辉 | 学号 | 2203080517 | | 专业 | 嵌入式技术应用
题 目 | 三项有感无刷电机驱动器硬件设计
指导教师 | 刘祥明/王玺伟 | | | 职 称 | | 讲师/工程师

指

导

教

师

意

见

论文选题符合要求，论述较得当，结构较合理，逻辑清晰。但在创新深度还不够，格式上也有些许不足，总体符合高职学生毕业论文要求，同意答辩

指导教师评分：　85 指导教师(签字)：

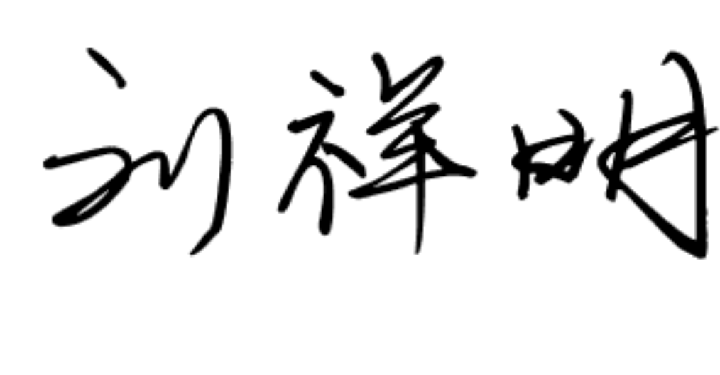
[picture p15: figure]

毕业设计（论文）评阅教师成绩评定表

姓 名 | 汤红辉 | 学号 | 2203080517 | | 专业 | 嵌入式技术应用
题 目 | 三项有感无刷电机驱动器
指导教师 | 刘祥明/王玺伟 | | | 职 称 | | 讲师/工程师
评 阅 教 师 意 见 | 该生论文《三项有感无刷电机驱动器》内容正确，有一定的独创性，分析问题严密，学生宿舍管理系统方案制定合理，实现方法较正确，实现了学生宿舍管理系统大部分功能，文字表述较准确，有较强解决问题能力。总体符合毕业设计要求，同意答辩。 评阅教师评分： 85 ；是否同意答辩： 是 评阅教师(签字)：

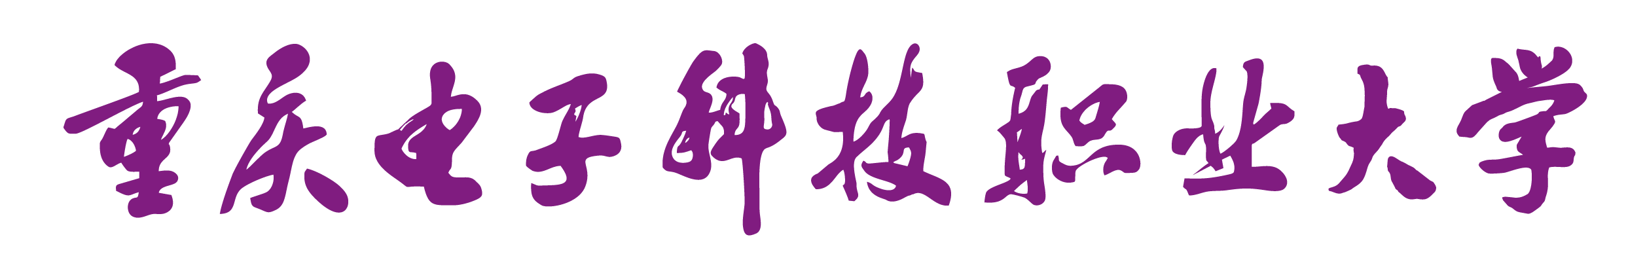
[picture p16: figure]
横式中文标准字－重电紫（电子屏幕使用版）(1)

毕业设计（论文）答辩记录及成绩评定表

姓名 | 汤红辉 | | 学号 | 2203080517 | 专业 | 嵌入式2202
题目 | 三项有感无刷电机驱动器硬件设计
答辩时间 | 2025年5月8日 | | | 答辩地点 | 致远楼424 | 答辩人数 | 51
答辩小组组长 | | 余永洪 | | | 答辩记录人 | 刘静
答辩小组成员 | | 余永洪、陈甫、刘静

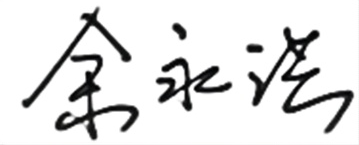
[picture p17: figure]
7b0a202020202266696c746572223a202230220a7d0a

答 辩 小 组 评 语 | 本课题通过对其结构及工作原理的研究，设计一种基于 STM32F407 的无刷直流电机控制系统I77，如何利用STM32F407VET6 的高级处理能力来实现复杂的控制算法。 该生论文选题具有一定的实际意义，研究目的和意义明确，研究方法正确，实现了系统设计的部分功能。通过答辩建议成绩为良好。 答辩成绩： 80 答辩小组成员签字： 答辩小组组长(签字)：

答辩记录：（应包括设计论文内容表述、答辩小组成员所提问题及学生对问题的回答）

为进一步挖据无刷直流电机的应用潜力，通过对其结构及工作原理的研究，设计一种基于 STM32F407 的无刷直流电机控制系统I77。本研究旨在结合STM32F407VET6 微控制器、EG2133 驱动芯片和 AS5600 位置传感器的优势，设计一款高性能的三相有感无刷电机驱动器。通过优化硬件设计和软件算法，提高驱动器的效率、可靠性和控制精度，以满足日益增长的高性能电机驱动需求。我们将深入研究如何利用STM32F407VET6 的高级处理能力来实现复杂的控制算法，同时通过EG2133 驱动芯片确保功率输出的稳定性和安全性，并通过AS5600位置传感器提供精确的位置反馈，进一步提升系统性能。此外，本研究还将探讨如何降低成本、简化设计复杂度，使所设计的驱动器更易于在实际应用中推广使用。通过本研究，我们希望能够为行业提供一种更加经济、高效且可靠的解决方案，从而促进BLDC电机驱动技术的进一步普及和发展。

提问1：这个软件的优点有哪些？

回答1：比较容易上手，有效的节约成本

提问2：里面有一些内容还是需要完善

回答2：好的

提问3：应用如何？

回答3：做一个人形机器人参加比赛，已经验证过了

答辩记录人：刘 静

2025 年 5 月 8 日

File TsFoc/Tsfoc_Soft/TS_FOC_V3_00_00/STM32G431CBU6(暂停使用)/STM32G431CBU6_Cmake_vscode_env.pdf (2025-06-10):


08/06/2025

STM32G431CBU6_Cmake_vscode_env Project Configuration Report

## 1. Description

### 1.1. Project

Project Name | STM32G431CBU6_Cmake_vscode _env
Board Name | custom
Generated with: | STM32CubeMX 6.14.1
Date | 06/08/2025

### 1.2. MCU

MCU Series | STM32G4
MCU Line | STM32G4x1
MCU name | STM32G431CBUx
MCU Package | UFQFPN48
MCU Pin number | 48

### 1.3. Core(s) information

Core(s) | ARM Cortex-M4

## 2. Pinout Configuration

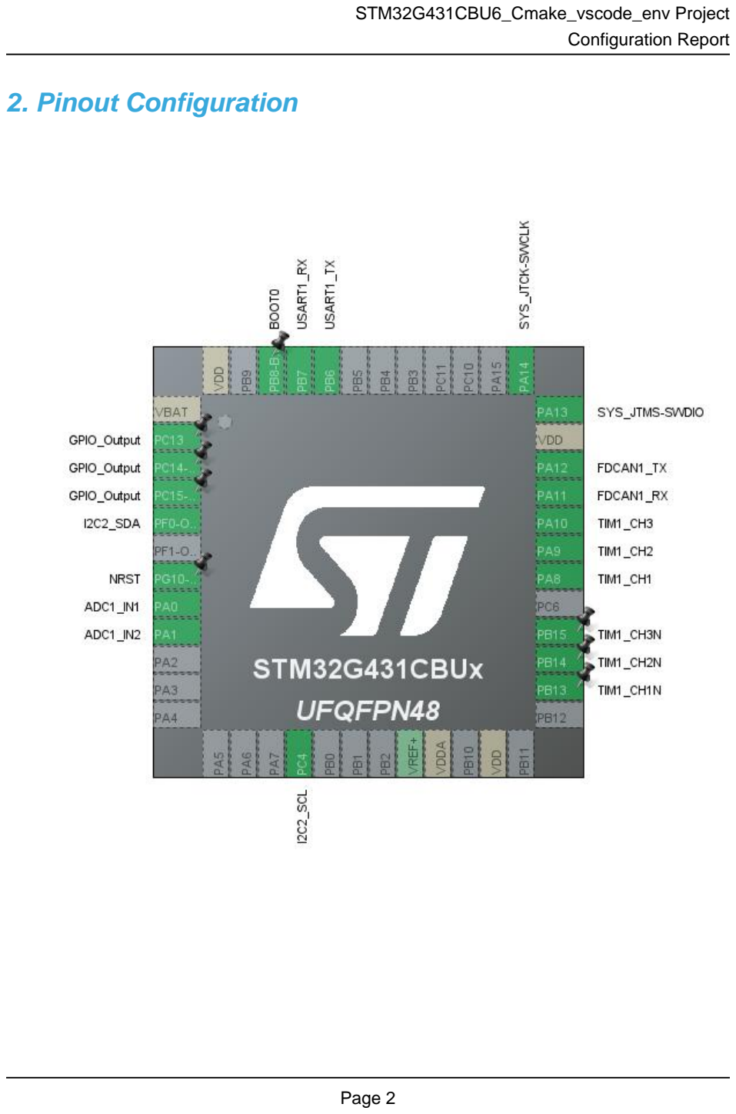
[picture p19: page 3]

## 3. Pins Configuration

Pin Number UFQFPN48 | Pin Name (function after reset) | Pin Type | Alternate Function(s) | Label
1 | VBAT | Power
2 | PC13 * | I/O | GPIO_Output
3 | PC14-OSC32_IN * | I/O | GPIO_Output
4 | PC15-OSC32_OUT * | I/O | GPIO_Output
5 | PF0-OSC_IN | I/O | I2C2_SDA
7 | PG10-NRST * | I/O | GPIO_Input | NRST
8 | PA0 | I/O | ADC1_IN1
9 | PA1 | I/O | ADC1_IN2
16 | PC4 | I/O | I2C2_SCL
21 | VDDA | Power
23 | VDD | Power
26 | PB13 | I/O | TIM1_CH1N
27 | PB14 | I/O | TIM1_CH2N
28 | PB15 | I/O | TIM1_CH3N
30 | PA8 | I/O | TIM1_CH1
31 | PA9 | I/O | TIM1_CH2
32 | PA10 | I/O | TIM1_CH3
33 | PA11 | I/O | FDCAN1_RX
34 | PA12 | I/O | FDCAN1_TX
35 | VDD | Power
36 | PA13 | I/O | SYS_JTMS-SWDIO
37 | PA14 | I/O | SYS_JTCK-SWCLK
44 | PB6 | I/O | USART1_TX
45 | PB7 | I/O | USART1_RX
46 | PB8-BOOT0 * | I/O | GPIO_Input | BOOT0
48 | VDD | Power

* The pin is affected with an I/O function

## 4. Clock Tree Configuration

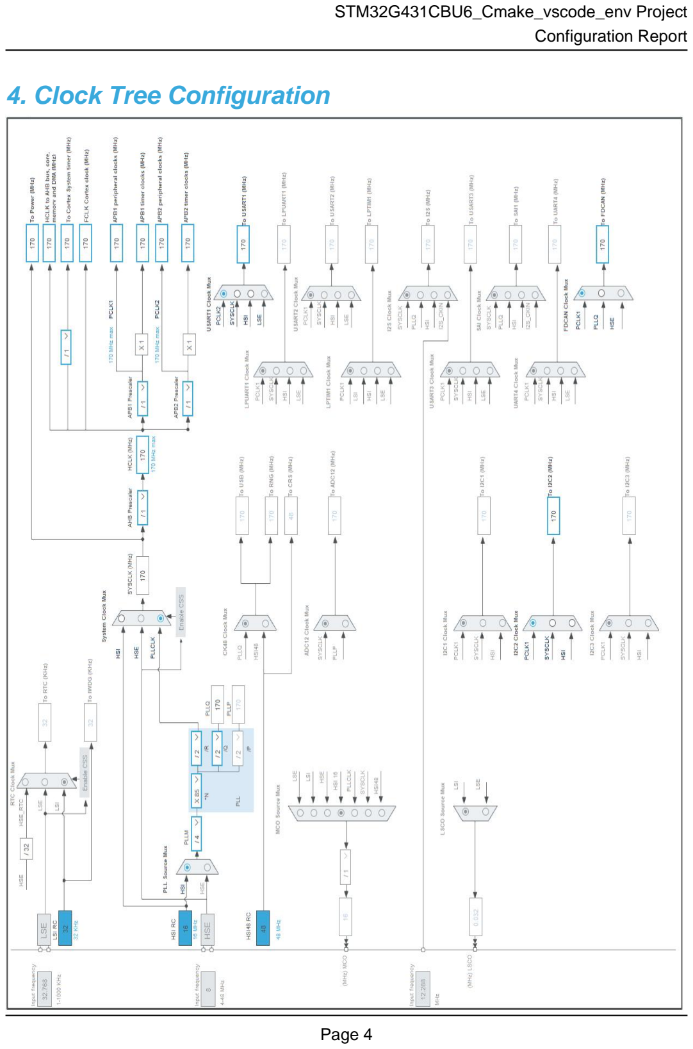
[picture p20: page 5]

## 1. Power Consumption Calculator report

### 1.1. Microcontroller Selection

Series | STM32G4
Line | STM32G4x1
MCU | STM32G431CBUx
Datasheet | DS12589_Rev0

### 1.2. Parameter Selection

Temperature | 25
Vdd | 3.0

### 1.3. Battery Selection

Battery | Li-SOCL2(A3400)
Capacity | 3400.0 mAh
Self Discharge | 0.08 %/month
Nominal Voltage | 3.6 V
Max Cont Current | 100.0 mA
Max Pulse Current | 200.0 mA
Cells in series | 1
Cells in parallel | 1

### 1.4. Sequence

Step | Step1 | Step2
Mode | RUN | STOP1
Vdd | 3.0 | 3.0
Voltage Source | Battery | Battery
Range | Range1-Boost | NoRange
Fetch Type | FLASH/ART | NA
CPU Frequency | 170 MHz | 0 Hz
Clock Configuration | HSE BYP PLL | ALL CLOCKS OFF
Clock Source Frequency | 4 MHz | 0 Hz
Peripherals
Additional Cons. | 0 mA | 0 mA
Average Current | 25.5 mA | 59 µA
Duration | 0.1 ms | 0.9 ms
DMIPS | 213.0 | 0.0
Ta Max | 127.71 | 129.99
Category | In DS Table | In DS Table

### 1.5. Results

Sequence Time | 1 ms | Average Current | 2.6 mA
Battery Life | 1 month, 23 days, 22 hours | Average DMIPS | 212.5 DMIPS

### 1.6. Chart

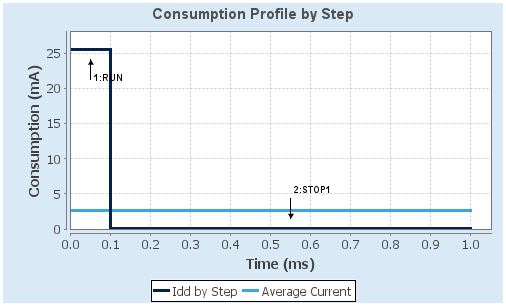
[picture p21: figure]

## 2. Software Project

### 2.1. Project Settings

Name | Value
Project Name | STM32G431CBU6_Cmake_vscode_env
Project Folder | C:\Users\dennis\Desktop\workspace\github_projects\FOC_L\TsFoc\Tsfoc_Soft\T
Toolchain / IDE | CMake
Firmware Package Name and Version | STM32Cube FW_G4 V1.6.1
Application Structure | Advanced
Generate Under Root | No
Do not generate the main() | No
Minimum Heap Size | 0x2000
Minimum Stack Size | 0x4000

### 2.2. Code Generation Settings

Name | Value
STM32Cube MCU packages and embedded software | Copy only the necessary library files
Generate peripheral initialization as a pair of '.c/.h' files | Yes
Backup previously generated files when re-generating | No
Keep User Code when re-generating | Yes
Delete previously generated files when not re-generated | Yes
Set all free pins as analog (to optimize the power consumption) | No
Enable Full Assert | No

### 2.3. Advanced Settings - Generated Function Calls

Rank | Function Name | Peripheral Instance Name
1 | SystemClock_Config | RCC
2 | MX_GPIO_Init | GPIO
3 | MX_DMA_Init | DMA
4 | MX_ADC1_Init | ADC1
5 | MX_FDCAN1_Init | FDCAN1
6 | MX_TIM1_Init | TIM1
7 | MX_I2C2_Init | I2C2
8 | MX_USART1_UART_Init | USART1

## 3. Peripherals and Middlewares Configuration

### 3.1. ADC1

IN1: IN1 Single-ended
IN2: IN2 Single-ended
3.1.1. Parameter Settings:

ADCs_Common_Settings:

Mode | Independent mode
ADC_Settings:
Clock Prescaler | Synchronous clock mode divided by 4
Resolution | ADC 12-bit resolution
Data Alignment | Right alignment
Gain Compensation | 0
Scan Conversion Mode | Enabled
End Of Conversion Selection | End of single conversion
Low Power Auto Wait | Disabled
Continuous Conversion Mode | Disabled
Discontinuous Conversion Mode | Disabled
DMA Continuous Requests | Enabled *
Overrun behaviour | Overrun data preserved
ADC_Regular_ConversionMode:
Enable Regular Conversions | Enable
Enable Regular Oversampling | Disable
Number Of Conversion | 2 *
External Trigger Conversion Source | Regular Conversion launched by software
External Trigger Conversion Edge | None
Rank | 1
Channel | Channel 1
Sampling Time | 6.5 Cycles *
Offset Number | No offset
Rank | 2 *
Channel | Channel 2 *
Sampling Time | 6.5 Cycles *
Offset Number | No offset
ADC_Injected_ConversionMode:
Enable Injected Conversions | Disable
Analog Watchdog 1:
Enable Analog WatchDog1 Mode | false
Analog Watchdog 2:

Enable Analog WatchDog2 Mode | false
Analog Watchdog 3:
Enable Analog WatchDog3 Mode | false

### 3.2. FDCAN1

mode: Activated
3.2.1. Parameter Settings:

Basic Parameters:

Clock Divider | Divide kernel clock by 1
Frame Format | Classic mode
Mode | Normal mode
Auto Retransmission | Disable
Transmit Pause | Disable
Protocol Exception | Disable
Nominal Sync Jump Width | 1
Data Prescaler | 1
Data Sync Jump Width | 1
Data Time Seg1 | 1
Data Time Seg2 | 1
Std Filters Nbr | 0
Ext Filters Nbr | 0
Tx Fifo Queue Mode | FIFO mode
Bit Timings Parameters:
Nominal Prescaler | 16
Nominal Time Quantum | 94.11764705882354 *
Nominal Time Seg1 | 1
Nominal Time Seg2 | 1
Nominal Time for one Bit | 282 *
Nominal Baud Rate | 3541666 *

### 3.3. I2C2

I2C: I2C
3.3.1. Parameter Settings:

Timing configuration:

Custom Timing | Disabled

I2C Speed Mode | Standard Mode
I2C Speed Frequency (KHz) | 100
Rise Time (ns) | 100
Fall Time (ns) | 100
Coefficient of Digital Filter | 0
Analog Filter | Enabled
Timing | 0x40B285C2 *
Slave Features:
Clock No Stretch Mode | Disabled
General Call Address Detection | Disabled
Primary Address Length selection | 7-bit
Dual Address Acknowledged | Disabled
Primary slave address | 0

### 3.4. RCC

3.4.1. Parameter Settings:

System Parameters:

VDD voltage (V) | 3.3
Instruction Cache | Enabled
Prefetch Buffer | Disabled
Data Cache | Enabled
Flash Latency(WS) | 4 WS (5 CPU cycle)
RCC Parameters:
HSI Calibration Value | 64
HSE Startup Timout Value (ms) | 100
LSE Startup Timout Value (ms) | 5000
Power Parameters:
Power Regulator Voltage Scale | Power Regulator Voltage Scale 1 boost
Peripherals Clock Configuration:
Generate the peripherals clock configuration | TRUE

### 3.5. SYS

Debug: Serial Wire
Timebase Source: SysTick
mode: save power of non-active UCPD - deactive Dead Battery pull-up

### 3.6. TIM1

Channel1: PWM Generation CH1 CH1N Channel2: PWM Generation CH2 CH2N Channel3: PWM Generation CH3 CH3N
3.6.1. Parameter Settings:

Counter Settings:

Prescaler (PSC - 16 bits value) | 0
Counter Mode | Up
Dithering | Disable
Counter Period (AutoReload Register - 16 bits value ) | 65535
Internal Clock Division (CKD) | No Division
Repetition Counter (RCR - 16 bits value) | 0
auto-reload preload | Disable
Trigger Output (TRGO) Parameters:
Master/Slave Mode (MSM bit) | Disable (Trigger input effect not delayed)
Trigger Event Selection TRGO | Reset (UG bit from TIMx_EGR)
Trigger Event Selection TRGO2 | Reset (UG bit from TIMx_EGR)
Break And Dead Time management - BRK Configuration:
BRK State | Disable
BRK Polarity | High
BRK Filter (4 bits value) | 0
BRK Sources Configuration
- Digital Input | Disable
- COMP1 | Disable
- COMP2 | Disable
- COMP3 | Disable
- COMP4 | Disable
Break And Dead Time management - BRK2 Configuration:
BRK2 State | Disable
BRK2 Polarity | High
BRK2 Filter (4 bits value) | 0
BRK2 Sources Configuration
- Digital Input | Disable
- COMP1 | Disable
- COMP2 | Disable
- COMP3 | Disable
- COMP4 | Disable
Break And Dead Time management - Output Configuration:
Automatic Output State | Disable

Off State Selection for Run Mode (OSSR) | Disable
Off State Selection for Idle Mode (OSSI) | Disable
Lock Configuration | Off
DeadTime Preload | Disable
Dead Time | 0
Asymmetrical DeadTime | Disable
Falling Dead Time | 0
Clear Input:
Clear Input Source | Disable
PWM Generation Channel 1 and 1N:
Mode | PWM mode 1
Pulse (16 bits value) | 0
Output compare preload | Enable
Fast Mode | Disable
CH Polarity | High
CHN Polarity | High
CH Idle State | Reset
CHN Idle State | Reset
PWM Generation Channel 2 and 2N:
Mode | PWM mode 1
Pulse (16 bits value) | 0
Output compare preload | Enable
Fast Mode | Disable
CH Polarity | High
CHN Polarity | High
CH Idle State | Reset
CHN Idle State | Reset
PWM Generation Channel 3 and 3N:
Mode | PWM mode 1
Pulse (16 bits value) | 0
Output compare preload | Enable
Fast Mode | Disable
CH Polarity | High
CHN Polarity | High
CH Idle State | Reset
CHN Idle State | Reset

### 3.7. USART1

Mode: Asynchronous

3.7.1. Parameter Settings:

Basic Parameters:

Baud Rate | 115200
Word Length | 8 Bits (including Parity)
Parity | None
Stop Bits | 1
Advanced Parameters:
Data Direction | Receive and Transmit
Over Sampling | 16 Samples
Single Sample | Disable
ClockPrescaler | 1
Fifo Mode | Disable
Txfifo Threshold | 1 eighth full configuration
Rxfifo Threshold | 1 eighth full configuration
Advanced Features:
Auto Baudrate | Disable
TX Pin Active Level Inversion | Disable
RX Pin Active Level Inversion | Disable
Data Inversion | Disable
TX and RX Pins Swapping | Disable
Overrun | Enable
DMA on RX Error | Enable
MSB First | Disable

* User modified value

## 4. System Configuration

### 4.1. GPIO configuration

IP | Pin | Signal | GPIO mode | GPIO pull/up pull down | Max Speed | User Label
ADC1 | PA0 | ADC1_IN1 | Analog mode | No pull-up and no pull-down | n/a
| PA1 | ADC1_IN2 | Analog mode | No pull-up and no pull-down | n/a
FDCAN1 | PA11 | FDCAN1_RX | Alternate Function Push Pull | No pull-up and no pull-down | Low
| PA12 | FDCAN1_TX | Alternate Function Push Pull | No pull-up and no pull-down | Low
I2C2 | PF0-OSC_IN | I2C2_SDA | Alternate Function Open Drain | No pull-up and no pull-down | Low
| PC4 | I2C2_SCL | Alternate Function Open Drain | No pull-up and no pull-down | Low
SYS | PA13 | SYS_JTMS-SWDIO | n/a | n/a | n/a
| PA14 | SYS_JTCK-SWCLK | n/a | n/a | n/a
TIM1 | PB13 | TIM1_CH1N | Alternate Function Push Pull | No pull-up and no pull-down | Low
| PB14 | TIM1_CH2N | Alternate Function Push Pull | No pull-up and no pull-down | Low
| PB15 | TIM1_CH3N | Alternate Function Push Pull | No pull-up and no pull-down | Low
| PA8 | TIM1_CH1 | Alternate Function Push Pull | No pull-up and no pull-down | Low
| PA9 | TIM1_CH2 | Alternate Function Push Pull | No pull-up and no pull-down | Low
| PA10 | TIM1_CH3 | Alternate Function Push Pull | No pull-up and no pull-down | Low
USART1 | PB6 | USART1_TX | Alternate Function Push Pull | No pull-up and no pull-down | Low
| PB7 | USART1_RX | Alternate Function Push Pull | No pull-up and no pull-down | Low
GPIO | PC13 | GPIO_Output | Output Push Pull | No pull-up and no pull-down | Low
| PC14-OSC32_IN | GPIO_Output | Output Push Pull | No pull-up and no pull-down | Low
| PC15-OSC32_OU T | GPIO_Output | Output Push Pull | No pull-up and no pull-down | Low
| PG10-NRST | GPIO_Input | Input mode | No pull-up and no pull-down | n/a | NRST
| PB8-BOOT0 | GPIO_Input | Input mode | No pull-up and no pull-down | n/a | BOOT0

### 4.2. DMA configuration

DMA request | Stream | Direction | Priority
ADC1 | DMA1_Channel1 | Peripheral To Memory | Low
USART1_RX | DMA1_Channel2 | Peripheral To Memory | Low

ADC1: DMA1_Channel1 DMA request Settings:

Mode: | Circular *
Peripheral Increment: | Disable
Memory Increment: | Enable *
Peripheral Data Width: | Half Word
Memory Data Width: | Half Word

USART1_RX: DMA1_Channel2 DMA request Settings:

Mode: | Normal
Peripheral Increment: | Disable
Memory Increment: | Enable *
Peripheral Data Width: | Byte
Memory Data Width: | Byte

### 4.3. NVIC configuration

4.3.1. NVIC
Interrupt Table | Enable | Preenmption Priority | SubPriority
Non maskable interrupt | true | 0 | 0
Hard fault interrupt | true | 0 | 0
Memory management fault | true | 0 | 0
Prefetch fault, memory access fault | true | 0 | 0
Undefined instruction or illegal state | true | 0 | 0
System service call via SWI instruction | true | 0 | 0
Debug monitor | true | 0 | 0
Pendable request for system service | true | 0 | 0
System tick timer | true | 15 | 0
DMA1 channel1 global interrupt | true | 0 | 0
DMA1 channel2 global interrupt | true | 0 | 0
ADC1 and ADC2 global interrupt | true | 0 | 0
FDCAN1 interrupt 0 | true | 0 | 0
FDCAN1 interrupt 1 | true | 0 | 0
USART1 global interrupt / USART1 wake-up interrupt through EXTI line 25 | true | 0 | 0
PVD/PVM1/PVM2/PVM3/PVM4 interrupts through EXTI lines 16/38/39/40/41 | | unused
Flash global interrupt | | unused
RCC global interrupt | | unused
TIM1 break interrupt and TIM15 global interrupt | | unused
TIM1 update interrupt and TIM16 global interrupt | | unused
TIM1 trigger and commutation interrupts and TIM17 global interrupt | | unused
TIM1 capture compare interrupt | | unused
I2C2 event interrupt / I2C2 wake-up interrupt through EXTI line 24 | | unused
I2C2 error interrupt | | unused
FPU global interrupt | | unused
4.3.2. NVIC Code generation

Enabled interrupt Table Select for init
sequence ordering
| | Generate IRQ
| | handler | Call HAL handler
Non maskable interrupt | false | true | false
Hard fault interrupt | false | true | false
Memory management fault | false | true | false
Prefetch fault, memory access fault | false | true | false

Enabled interrupt Table | Select for init sequence ordering | Generate IRQ handler | Call HAL handler
Undefined instruction or illegal state | false | true | false
System service call via SWI instruction | false | true | false
Debug monitor | false | true | false
Pendable request for system service | false | true | false
System tick timer | false | true | true
DMA1 channel1 global interrupt | false | true | true
DMA1 channel2 global interrupt | false | true | true
ADC1 and ADC2 global interrupt | false | true | true
FDCAN1 interrupt 0 | false | true | true
FDCAN1 interrupt 1 | false | true | true
USART1 global interrupt / USART1 wake-up interrupt through EXTI line 25 | false | true | true

* User modified value

## 5. System Views

5.1. Category view
5.1.1. Current

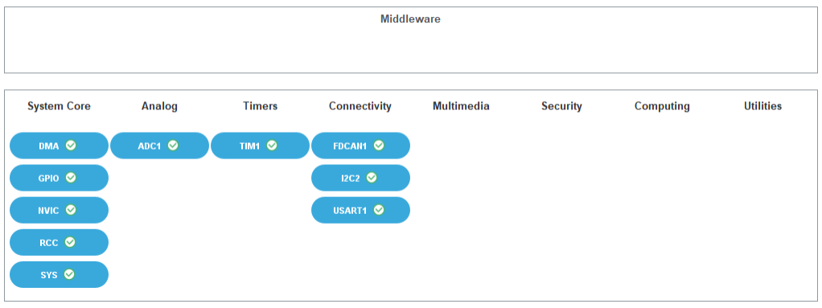
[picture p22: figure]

## 6. Docs & Resources

Type | Link
BSDL files | https://www.st.com/resource/en/bsdl_model/stm32g4_bsdl.zip
IBIS models | https://www.st.com/resource/en/ibis_model/stm32g4_ibis.zip
System View Description | https://www.st.com/resource/en/svd/stm32g4_svd.zip
Presentations | https://www.st.com/resource/en/product_presentation/stm32-stm8_embedded_software_solutions.pdf
Presentations | https://www.st.com/resource/en/product_presentation/stm32_eval-tools_portfolio.pdf
Presentations | https://www.st.com/resource/en/product_presentation/stm32_stm8_functi onal-safety-packages.pdf
Presentations | https://www.st.com/resource/en/product_presentation/stm32-usb-c-pd-solutions-presentation.pdf
Presentations | https://www.st.com/resource/en/product_presentation/stm32-stm8_software_development_tools.pdf
Presentations | https://www.st.com/resource/en/product_presentation/microcontrollers-stm32-family-overview.pdf
Presentations | https://www.st.com/resource/en/product_presentation/microcontrollers-stm32g4-series-product-overview.pdf
Brochures | https://www.st.com/resource/en/brochure/products-and-solutions-for-plcs-and-smart-i-os.pdf
Flyers | https://www.st.com/resource/en/flyer/flstm32g4.pdf
Flyers | https://www.st.com/resource/en/flyer/flstm32nucleo.pdf
Flyers | https://www.st.com/resource/en/flyer/flstm32trust.pdf
Flyers | https://www.st.com/resource/en/flyer/fldpstpfc11120.pdf
Application Notes | https://www.st.com/resource/en/application_note/an1709-emc-design-guide-for-stm8-stm32-and-legacy-mcus-stmicroelectronics.pdf
Application Notes | https://www.st.com/resource/en/application_note/an2606-stm32-microcontroller-system-memory-boot-mode-stmicroelectronics.pdf
Application Notes | https://www.st.com/resource/en/application_note/an3126-audio-and-

| waveform-generation-using-the-dac-in-stm32-products-stmicroelectronics.pdf
Application Notes | https://www.st.com/resource/en/application_note/an3155-usart-protocol-used-in-the-stm32-bootloader-stmicroelectronics.pdf
Application Notes | https://www.st.com/resource/en/application_note/an3156-usb-dfu-protocol-used-in-the-stm32-bootloader-stmicroelectronics.pdf
Application Notes | https://www.st.com/resource/en/application_note/an4221-i2c-protocol-used-in-the-stm32-bootloader-stmicroelectronics.pdf
Application Notes | https://www.st.com/resource/en/application_note/an4232-getting-started-with-analog-comparators-for-stm32f3-series-and-stm32g4-series-devices-stmicroelectronics.pdf
Application Notes | https://www.st.com/resource/en/application_note/an4286-spi-protocol-used-in-the-stm32-bootloader-stmicroelectronics.pdf
Application Notes | https://www.st.com/resource/en/application_note/an4296-use-stm32f3stm32g4-ccm-sram-with-iar-embedded-workbench-keil-mdkarm-stmicroelectronics-stm32cubeide-and-other-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
Application Notes | https://www.st.com/resource/en/application_note/an4566-extending-the-dac-performance-of-stm32-microcontrollers-stmicroelectronics.pdf
Application Notes | https://www.st.com/resource/en/application_note/an4655-virtually-increasing-the-number-of-serial-communication-peripherals-in-stm32-applications-stmicroelectronics.p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
Application Notes | https://www.st.com/resource/en/application_note/an4750-handling-of-soft-errors-in-stm32-applications-stmicroelectronics.pdf
Application Notes | https://www.st.com/resource/en/application_note/an4776-generalpurpose-timer-cookbook-for-stm32-microcontrollers-stmicroelectronics.pdf
Application Notes | https://www.st.com/resource/en/application_note/an4803-highspeed-si-simulations-using-ibis-and-boardlevel-simulations-using-hyperlynx-si-on-stm32-mcus-and-mpus-stmic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
Application Notes | https://www.st.com/resource/en/application_note/an4989-stm32-microcontroller-debug-toolbox-stmicroelectronics.pdf
Application Notes | https://www.st.com/resource/en/application_note/an5027-interfacing-pdm-digital-microphones-using-stm32-mcus-and-mpus-stmicroelectronics.pdf

Application Notes | https://www.st.com/resource/en/application_note/an5093-getting-started-with-stm32g4-series--hardware-development-boards-stmicroelectronics.pdf
Application Notes | https://www.st.com/resource/en/application_note/an5306-operational-amplifier-opamp-usage-in-stm32g4-series-stmicroelectronics.pdf
Application Notes | https://www.st.com/resource/en/application_note/an5310-guideline-for-using-analog-features-of-stm32g4-series-versus-stm32f3-series-devices-stmicroelectronics.pdf
Application Notes | https://www.st.com/resource/en/application_note/an5315-stm32cube-firmware-examples-for-stm32g4-series-stmicroelectronics.pdf
Application Notes | https://www.st.com/resource/en/application_note/an5346-stm32g4-adc-use-tips-and-recommendations-stmicroelectronics.pdf
Application Notes | https://www.st.com/resource/en/application_note/an5094-migrating-between-stm32f334303-lines-and-stm32g431xxg474xxg491xx-microcontrollers-stmicroelectronics.pdf
Application Notes | https://www.st.com/resource/en/application_note/an5738-stm32g4-series-lifetime-estimates-stmicroelectronics.pdf
Application Notes | https://www.st.com/resource/en/application_note/an4899-stm32-microcontroller-gpio-hardware-settings-and-lowpower-consumption-stmicroelectronics.pdf
Application Notes | https://www.st.com/resource/en/application_note/an5612-esd-protection-of-stm32-mcus-and-mpus-stmicroelectronics.pdf
Application Notes | https://www.st.com/resource/en/application_note/an4991-how-to-wake-up-an-stm32-microcontroller-from-lowpower-mode-with-the-usart-or-the-lpuart-stmicroelectronics.pdf
Application Notes | https://www.st.com/resource/en/application_note/an4838-introduction-to-memory-protection-unit-management-on-stm32-mcus-stmicroelectronics.pdf
Application Notes | https://www.st.com/resource/en/application_note/an5325-how-to-use-the-cordic-to-perform-mathematical-functions-on-stm32-mcus-stmicroelectronics.pdf
Application Notes | https://www.st.com/resource/en/application_note/an5225-introduction-to-usb-typec-power-delivery-for-stm32-mcus-and-mpus-stmicroelectronics.pdf

Application Notes | https://www.st.com/resource/en/application_note/an4894-how-to-use-eeprom-emulation-on-stm32-mcus-stmicroelectronics.pdf
Application Notes | https://www.st.com/resource/en/application_note/an5537-how-to-use-adc-oversampling-techniques-to-improve-signaltonoise-ratio-on-stm32-mcus-stmicroelectronics.pdf
Application Notes | https://www.st.com/resource/en/application_note/an5036-guidelines-for-thermal-management-on-stm32-applications-stmicroelectronics.pdf
Application Notes | https://www.st.com/resource/en/application_note/an5405-how-to-use-fdcan-bootloader-protocol-on-stm32-mcus-stmicroelectronics.pdf
Application Notes | https://www.st.com/resource/en/application_note/an5978-introduction-to-mb1971-llc-hat-12-v-to-75-v1-a-for-f334-g474-nucleo-board-stmicroelectronics.pdf
Application Notes | https://www.st.com/resource/en/application_note/an5690-how-to-use-vrefbuf-peripheral-on-stm32-mcus-and-mpus-stmicroelectronics.pdf
Application Notes | https://www.st.com/resource/en/application_note/an4230-introduction-to-random-number-generation-validation-using-the-nist-statistical-test-suite-for-stm32-mcus-and-m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
Application Notes | https://www.st.com/resource/en/application_note/an2548-introduction-to-dma-controller-for-stm32-mcus-stmicroelectronics.pdf
Application Notes | https://www.st.com/resource/en/application_note/an4013-introduction-to-timers-for-stm32-mcus-stmicroelectronics.pdf
Application Notes | https://www.st.com/resource/en/application_note/an4277-how-to-use-pwm-shutdown-for-motor-control-and-digital-power-conversion-on-stm32-mcus-stmicroelectronics.pdf
Application Notes | https://www.st.com/resource/en/application_note/an4635-how-to-optimize-lpuart-power-consumption-on-stm32-mcus-stmicroelectronics.pdf
Application Notes | https://www.st.com/resource/en/application_note/an4759-introduction-to-using-the-hardware-realtime-clock-rtc-and-the-tamper-management-unit-tamp-with-stm32-mcus-stmi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
Application Notes | https://www.st.com/resource/en/application_note/an4908-getting-started-with-usart-automatic-baud-rater-detection-for-stm32-mcus-stmicroelectronics.pdf

Application Notes | https://www.st.com/resource/en/application_note/an5156-introduction-to-security-for-stm32-mcus-stmicroelectronics.pdf
Application Notes | https://www.st.com/resource/en/application_note/an5224-introduction-to-dmamux-for-stm32-mcus-stmicroelectronics.pdf
Application Notes | https://www.st.com/resource/en/application_note/an5543-guidelines-for-enhanced-spi-communication-on-stm32-mcus-and-mpus-stmicroelectronics.pdf
Application Notes | https://www.st.com/resource/en/application_note/an5348-introduction-to-fdcan-peripherals-for-stm32-mcus-stmicroelectronics.pdf
Application Notes | https://www.st.com/resource/en/application_note/cd00211314-how-to-optimize-the-adc-accuracy-in-the-stm32-mcus-stmicroelectronics.pdf
Application Notes | https://www.st.com/resource/en/application_note/an2639-soldering-recommendations-and-package-information-for-leadfree-ecopack2-mcus-and-mpus-stmicroelectronics.pdf
Application Notes for related Tools & Software | https://www.st.com/resource/en/application_note/an4435-guidelines-for-obtaining-ulcsaiec-607301603351-class-b-certification-in-any-stm32-application-stmicroelectroni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
Application Notes for related Tools & Software | https://www.st.com/resource/en/application_note/an4657-stm32-inapplication-programming-iap-using-the-usart-stmicroelectronics.pdf
Application Notes for related Tools & Software | https://www.st.com/resource/en/application_note/an4841-digital-signal-processing-for-stm32-microcontrollers-using-cmsis-stmicroelectronics.pdf
Application Notes for related Tools & Software | https://www.st.com/resource/en/application_note/an5056-integration-guide-for-the-xcubesbsfu-stm32cube-expansion-package-stmicroelectronics.pdf
Application Notes for related Tools & Software | https://www.st.com/resource/en/application_note/an5305-digital-filter-implementation-with-the-fmac-using-stm32cubeg4-mcu-package-stmicroelectronics.pdf
Application Notes for related Tools & Software | https://www.st.com/resource/en/application_note/an5315-stm32cube-firmware-examples-for-stm32g4-series-stmicroelectronics.pdf

Application Notes
for related Tools

https://www.st.com/resource/en/application_note/an5345-highbrightnessrgb-led-control-using-the-bg474edpow1-discovery-kit-

& Software | stmicroelectronics.pdf
Application Notes for related Tools & Software | https://www.st.com/resource/en/application_note/an5360-getting-started-with-projects-based-on-the-stm32mp1-series-in-stm32cubeide-stmicroelectronics.pdf
Application Notes for related Tools & Software | https://www.st.com/resource/en/application_note/an5361-getting-started-with-projects-based-on-dualcore-stm32h7-microcontrollers-in-stm32cubeide-stmicroelectronics.pd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
Application Notes for related Tools & Software | https://www.st.com/resource/en/application_note/an5394-getting-started-with-projects-based-on-the-stm32l5-series-in-stm32cubeide-stmicroelectronics.pdf
Application Notes for related Tools & Software | https://www.st.com/resource/en/application_note/an5418-how-to-build-a-simple-usbpd-sink-application-with-stm32cubemx-stmicroelectronics.pdf
Application Notes for related Tools & Software | https://www.st.com/resource/en/application_note/an5426-migrating-graphics-middleware-projects-from-stm32cubemx-540-to-stm32cubemx-550-stmicroelectronics.pdf
Application Notes for related Tools & Software | https://www.st.com/resource/en/application_note/an5464-position-control-of-a-threephase-permanent-magnet-motor-using-xcubemcsdk-or-xcubemcsdkful-stmicroelectronics.p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
Application Notes for related Tools & Software | https://www.st.com/resource/en/application_note/an5564-getting-started-with-projects-based-on-dualcore-stm32wl-microcontrollers-in-stm32cubeide-stmicroelectronics.pd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
Application Notes for related Tools & Software | https://www.st.com/resource/en/application_note/an5698-adapting-the-xcubestl-functional-safety-package-for-stm32-iec-61508-compliant-to-other-safety-standards-stmicr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
Application Notes for related Tools & Software | https://www.st.com/resource/en/application_note/an5731-stm32cubemx-and-stm32cubeide-threadsafe-solution-stmicroelectronics.pdf
Application Notes for related Tools & Software | https://www.st.com/resource/en/application_note/an5785-boost-voltage-mode-on-bg474edpow1-discovery-kit-stmicroelectronics.pdf
Application Notes for related Tools & Software | https://www.st.com/resource/en/application_note/an5788-stm32-digital-power-pid-and-iir-filters-for-smps-control-design-and-comparison-on-bg414edpow1-discovery-kit-st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

Application Notes for related Tools & Software | https://www.st.com/resource/en/application_note/an4502-stm32-smbuspmbus-expansion-package-for-stm32cube-stmicroelectronics.pdf
Application Notes for related Tools & Software | https://www.st.com/resource/en/application_note/an5952-how-to-use-cmake-in-stm32cubeide-stmicroelectronics.pdf
Application Notes for related Tools & Software | https://www.st.com/resource/en/application_note/an4635-how-to-optimize-lpuart-power-consumption-on-stm32-mcus-stmicroelectronics.pdf
Application Notes for related Tools & Software | https://www.st.com/resource/en/application_note/an5054-how-to-perform-secure-programming-using-stm32cubeprogrammer-stmicroelectronics.pdf
Application Notes for related Tools & Software | https://www.st.com/resource/en/application_note/an5496-guidelines-for-the-buck-voltage-mode-on-the-bg474edpow1-discovery-kit-stmicroelectronics.pdf
Application Notes for related Tools & Software | https://www.st.com/resource/en/application_note/an5497-introduction-to-the-buck-current-mode-with-the-bg474edpow1-discovery-kit-stmicroelectronics.pdf
Application Notes for related Tools & Software | https://www.st.com/resource/en/application_note/an6179-how-to-integrate-the-stl-firmware-into-a-time-critical-user-application-stmicroelectronics.pdf
Errata Sheets | https://www.st.com/resource/en/errata_sheet/es0431-stm32g431xx441xx-device-errata-stmicroelectronics.pdf
Datasheet | https://www.st.com/resource/en/datasheet/dm00507199.pdf
Programming Manuals | https://www.st.com/resource/en/programming_manual/pm0214-stm32-cortexm4-mcus-and-mpus-programming-manual-stmicroelectronics.pdf
Reference Manuals | https://www.st.com/resource/en/reference_manual/rm0440-stm32g4-series-advanced-armbased-32bit-mcus-stmicroelectronics.pdf
Technical Notes & Articles | https://www.st.com/resource/en/technical_note/tn1163-description-of-wlcsp-for-microcontrollers-and-recommendations-for-its-use-stmicroelectronics.pdf
Technical Notes & Articles | https://www.st.com/resource/en/technical_note/tn1204-tape-and-reel-shipping-media-for-stm32-microcontrollers-in-bga-packages-stmicroelectronics.pdf

Technical Notes & Articles | https://www.st.com/resource/en/technical_note/tn1205-tape-and-reel-shipping-media-for-stm8-and-stm32-microcontrollers-in-fpn-packages-stmicroelectronics.pdf
Technical Notes & Articles | https://www.st.com/resource/en/technical_note/tn1206-tape-and-reel-shipping-media-for-stm8-and-stm32-microcontrollers-in-qfp-packages-stmicroelectronics.pdf
Technical Notes & Articles | https://www.st.com/resource/en/technical_note/tn1207-tape-and-reel-shipping-media-for-stm8-and-stm32-microcontrollers-in-so-packages-stmicroelectronics.pdf
Technical Notes & Articles | https://www.st.com/resource/en/technical_note/tn1208-tape-and-reel-shipping-media-for-stm8-and-stm32-microcontrollers-in-tssop-and-ssop-packages-stmicroelectronics.p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
Technical Notes & Articles | https://www.st.com/resource/en/technical_note/tn1433-reference-device-marking-schematics-for-stm32-microcontrollers-and-microprocessors-stmicroelectronics.pdf
Technical Notes & Articles | https://www.st.com/resource/en/technical_note/tn1489-security-bulletin-tn1489stpsirt-physical-attacks-on-stm32-and-stm32cube-firmware-stmicroelectronics.pdf
User Manuals | https://www.st.com/resource/en/user_manual/um3167-stm32g4-series-ulcsaiec-607301603351-selftest-library-user-guide-stmicroelectronics.pdf

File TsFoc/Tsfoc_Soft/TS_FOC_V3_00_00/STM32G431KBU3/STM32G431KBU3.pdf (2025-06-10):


08/06/2025

STM32G431KBU3 Project
Configuration Report

## 1. Description

### 1.1. Project

Project Name | STM32G431KBU3
Board Name | custom
Generated with: | STM32CubeMX 6.14.1
Date | 06/08/2025

### 1.2. MCU

MCU Series | STM32G4
MCU Line | STM32G4x1
MCU name | STM32G431KBUx
MCU Package | UFQFPN32
MCU Pin number | 32

### 1.3. Core(s) information

Core(s) | ARM Cortex-M4

## 2. Pinout Configuration

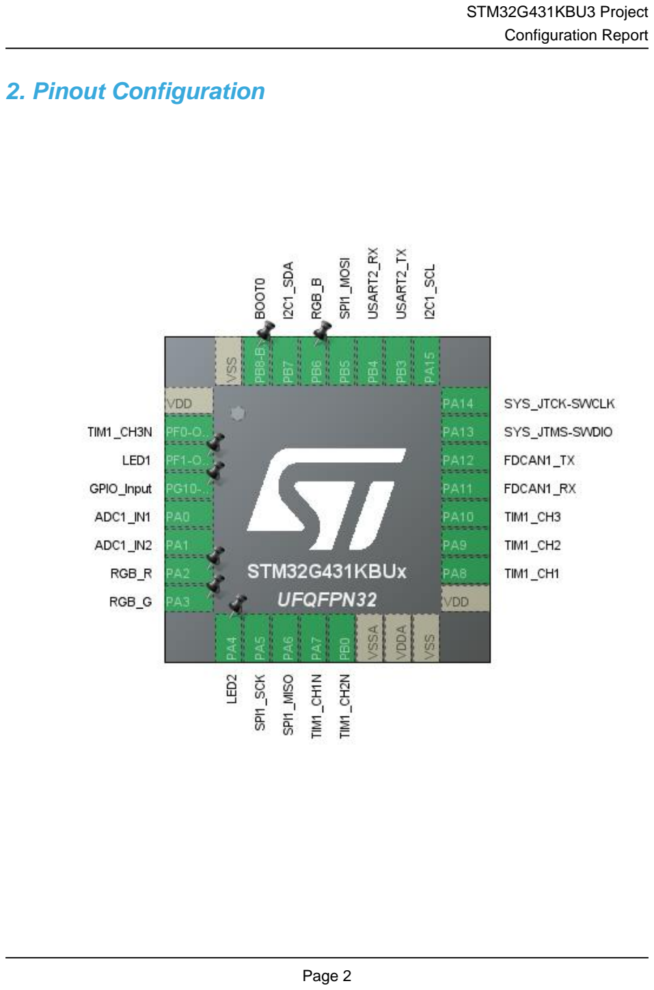
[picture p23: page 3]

## 3. Pins Configuration

Pin Number UFQFPN32 | Pin Name (function after reset) | Pin Type | Alternate Function(s) | Label
1 | VDD | Power
2 | PF0-OSC_IN | I/O | TIM1_CH3N
3 | PF1-OSC_OUT * | I/O | GPIO_Output | LED1
4 | PG10-NRST * | I/O | GPIO_Input
5 | PA0 | I/O | ADC1_IN1
6 | PA1 | I/O | ADC1_IN2
7 | PA2 | I/O | TIM2_CH3 | RGB_R
8 | PA3 | I/O | TIM2_CH4 | RGB_G
9 | PA4 * | I/O | GPIO_Output | LED2
10 | PA5 | I/O | SPI1_SCK
11 | PA6 | I/O | SPI1_MISO
12 | PA7 | I/O | TIM1_CH1N
13 | PB0 | I/O | TIM1_CH2N
14 | VSSA | Power
15 | VDDA | Power
16 | VSS | Power
17 | VDD | Power
18 | PA8 | I/O | TIM1_CH1
19 | PA9 | I/O | TIM1_CH2
20 | PA10 | I/O | TIM1_CH3
21 | PA11 | I/O | FDCAN1_RX
22 | PA12 | I/O | FDCAN1_TX
23 | PA13 | I/O | SYS_JTMS-SWDIO
24 | PA14 | I/O | SYS_JTCK-SWCLK
25 | PA15 | I/O | I2C1_SCL
26 | PB3 | I/O | USART2_TX
27 | PB4 | I/O | USART2_RX
28 | PB5 | I/O | SPI1_MOSI
29 | PB6 | I/O | TIM8_CH1 | RGB_B
30 | PB7 | I/O | I2C1_SDA
31 | PB8-BOOT0 * | I/O | GPIO_Input | BOOT0
32 | VSS | Power

* The pin is affected with an I/O function

## 4. Clock Tree Configuration

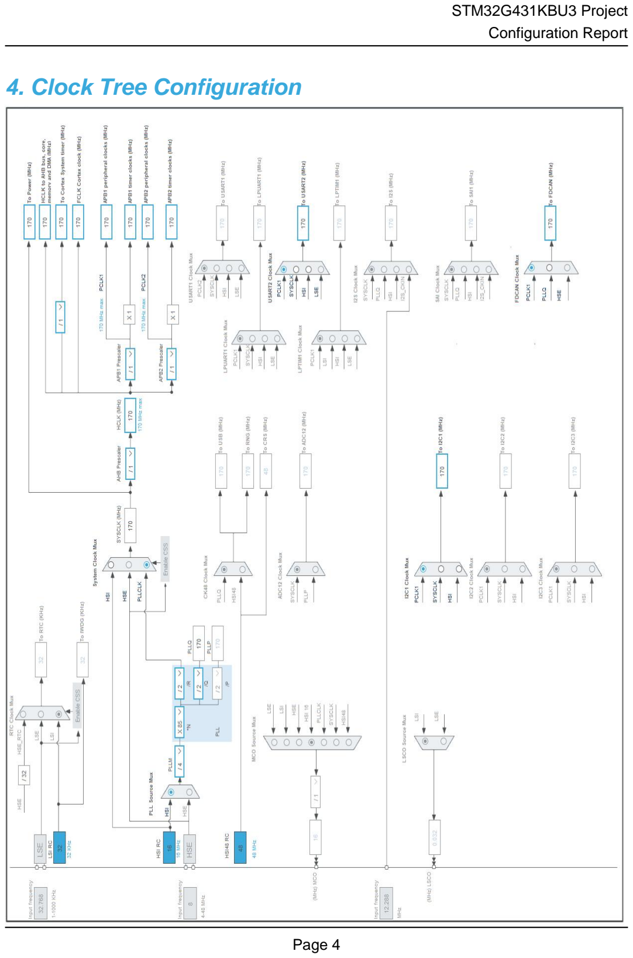
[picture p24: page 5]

## 1. Power Consumption Calculator report

### 1.1. Microcontroller Selection

Series | STM32G4
Line | STM32G4x1
MCU | STM32G431KBUx
Datasheet | DS12589_Rev0

### 1.2. Parameter Selection

Temperature | 25
Vdd | 3.0

### 1.3. Battery Selection

Battery | Li-SOCL2(A3400)
Capacity | 3400.0 mAh
Self Discharge | 0.08 %/month
Nominal Voltage | 3.6 V
Max Cont Current | 100.0 mA
Max Pulse Current | 200.0 mA
Cells in series | 1
Cells in parallel | 1

### 1.4. Sequence

Step | Step1 | Step2
Mode | RUN | STOP1
Vdd | 3.0 | 3.0
Voltage Source | Battery | Battery
Range | Range1-Boost | NoRange
Fetch Type | FLASH/ART | NA
CPU Frequency | 170 MHz | 0 Hz
Clock Configuration | HSE BYP PLL | ALL CLOCKS OFF
Clock Source Frequency | 4 MHz | 0 Hz
Peripherals
Additional Cons. | 0 mA | 0 mA
Average Current | 25.5 mA | 59 µA
Duration | 0.1 ms | 0.9 ms
DMIPS | 213.0 | 0.0
Ta Max | 127.4 | 129.99
Category | In DS Table | In DS Table

### 1.5. Results

Sequence Time | 1 ms | Average Current | 2.6 mA
Battery Life | 1 month, 23 days, 22 hours | Average DMIPS | 212.5 DMIPS

### 1.6. Chart


## 2. Software Project

### 2.1. Project Settings

Name | Value
Project Name | STM32G431KBU3
Project Folder | C:\Users\dennis\Desktop\workspace\github_projects\FOC_L\TsFoc\Tsfoc_Soft\T
Toolchain / IDE | CMake
Firmware Package Name and Version | STM32Cube FW_G4 V1.6.1
Application Structure | Advanced
Generate Under Root | No
Do not generate the main() | No
Minimum Heap Size | 0x2000
Minimum Stack Size | 0x4000

### 2.2. Code Generation Settings

Name | Value
STM32Cube MCU packages and embedded software | Copy only the necessary library files
Generate peripheral initialization as a pair of '.c/.h' files | Yes
Backup previously generated files when re-generating | No
Keep User Code when re-generating | Yes
Delete previously generated files when not re-generated | Yes
Set all free pins as analog (to optimize the power consumption) | No
Enable Full Assert | No

### 2.3. Advanced Settings - Generated Function Calls

Rank | Function Name | Peripheral Instance Name
1 | SystemClock_Config | RCC
2 | MX_GPIO_Init | GPIO
3 | MX_DMA_Init | DMA
4 | MX_ADC1_Init | ADC1
5 | MX_FDCAN1_Init | FDCAN1
6 | MX_I2C1_Init | I2C1
7 | MX_TIM1_Init | TIM1
8 | MX_USART2_UART_Init | USART2
9 | MX_SPI1_Init | SPI1
10 | MX_TIM2_Init | TIM2
11 | MX_TIM8_Init | TIM8

## 3. Peripherals and Middlewares Configuration

### 3.1. ADC1

IN1: IN1 Single-ended
IN2: IN2 Single-ended
3.1.1. Parameter Settings:

ADCs_Common_Settings:

Mode | Independent mode
ADC_Settings:
Clock Prescaler | Synchronous clock mode divided by 4
Resolution | ADC 12-bit resolution
Data Alignment | Right alignment
Gain Compensation | 0
Scan Conversion Mode | Enabled
End Of Conversion Selection | End of single conversion
Low Power Auto Wait | Disabled
Continuous Conversion Mode | Enabled *
Discontinuous Conversion Mode | Disabled
DMA Continuous Requests | Enabled *
Overrun behaviour | Overrun data preserved
ADC_Regular_ConversionMode:
Enable Regular Conversions | Enable
Enable Regular Oversampling | Disable
Number Of Conversion | 2 *
External Trigger Conversion Source | Regular Conversion launched by software
External Trigger Conversion Edge | None
Rank | 1
Channel | Channel 1
Sampling Time | 6.5 Cycles *
Offset Number | No offset
Rank | 2 *
Channel | Channel 2 *
Sampling Time | 6.5 Cycles *
Offset Number | No offset
ADC_Injected_ConversionMode:
Enable Injected Conversions | Disable
Analog Watchdog 1:
Enable Analog WatchDog1 Mode | false
Analog Watchdog 2:

Enable Analog WatchDog2 Mode | false
Analog Watchdog 3:
Enable Analog WatchDog3 Mode | false

### 3.2. FDCAN1

mode: Activated
3.2.1. Parameter Settings:

Basic Parameters:

Clock Divider | Divide kernel clock by 1
Frame Format | Classic mode
Mode | Normal mode
Auto Retransmission | Disable
Transmit Pause | Disable
Protocol Exception | Disable
Nominal Sync Jump Width | 1
Data Prescaler | 1
Data Sync Jump Width | 1
Data Time Seg1 | 1
Data Time Seg2 | 1
Std Filters Nbr | 0
Ext Filters Nbr | 0
Tx Fifo Queue Mode | FIFO mode
Bit Timings Parameters:
Nominal Prescaler | 16
Nominal Time Quantum | 94.11764705882354 *
Nominal Time Seg1 | 1
Nominal Time Seg2 | 1
Nominal Time for one Bit | 282 *
Nominal Baud Rate | 3541666 *

### 3.3. I2C1

I2C: I2C
3.3.1. Parameter Settings:

Timing configuration:

Custom Timing | Disabled

I2C Speed Mode | Fast Mode *
I2C Speed Frequency (KHz) | 400
Rise Time (ns) | 100
Fall Time (ns) | 100
Coefficient of Digital Filter | 0
Analog Filter | Enabled
Timing | 0x40621236 *
Slave Features:
Clock No Stretch Mode | Disabled
General Call Address Detection | Disabled
Primary Address Length selection | 7-bit
Dual Address Acknowledged | Disabled
Primary slave address | 0

### 3.4. RCC

3.4.1. Parameter Settings:

System Parameters:

VDD voltage (V) | 3.3
Instruction Cache | Enabled
Prefetch Buffer | Disabled
Data Cache | Enabled
Flash Latency(WS) | 4 WS (5 CPU cycle)
RCC Parameters:
HSI Calibration Value | 64
HSE Startup Timout Value (ms) | 100
LSE Startup Timout Value (ms) | 5000
Power Parameters:
Power Regulator Voltage Scale | Power Regulator Voltage Scale 1 boost
Peripherals Clock Configuration:
Generate the peripherals clock configuration | TRUE

### 3.5. SPI1

Mode: Full-Duplex Master
3.5.1. Parameter Settings:

Basic Parameters:

Frame Format | Motorola
Data Size | 4 Bits
First Bit | MSB First
Clock Parameters:
Prescaler (for Baud Rate) | 8 *
Baud Rate | 21.25 MBits/s *
Clock Polarity (CPOL) | Low
Clock Phase (CPHA) | 1 Edge
Advanced Parameters:
CRC Calculation | Disabled
NSSP Mode | Enabled
NSS Signal Type | Software

### 3.6. SYS

Debug: Serial Wire
Timebase Source: SysTick
mode: save power of non-active UCPD - deactive Dead Battery pull-up

### 3.7. TIM1

Channel1: PWM Generation CH1 CH1N
Channel2: PWM Generation CH2 CH2N
Channel3: PWM Generation CH3 CH3N
3.7.1. Parameter Settings:

Counter Settings:

Prescaler (PSC - 16 bits value) | 1-1
Counter Mode | Up
Dithering | Disable
Counter Period (AutoReload Register - 16 bits value ) | 65535
Internal Clock Division (CKD) | No Division
Repetition Counter (RCR - 16 bits value) | 0
auto-reload preload | Enable *
Trigger Output (TRGO) Parameters:
Master/Slave Mode (MSM bit) | Disable (Trigger input effect not delayed)
Trigger Event Selection TRGO | Reset (UG bit from TIMx_EGR)
Trigger Event Selection TRGO2 | Reset (UG bit from TIMx_EGR)
Break And Dead Time management - BRK Configuration:
BRK State | Disable

BRK Polarity | High
BRK Filter (4 bits value) | 0
BRK Sources Configuration
- Digital Input | Disable
- COMP1 | Disable
- COMP2 | Disable
- COMP3 | Disable
- COMP4 | Disable
Break And Dead Time management - BRK2 Configuration:
BRK2 State | Disable
BRK2 Polarity | High
BRK2 Filter (4 bits value) | 0
BRK2 Sources Configuration
- Digital Input | Disable
- COMP1 | Disable
- COMP2 | Disable
- COMP3 | Disable
- COMP4 | Disable
Break And Dead Time management - Output Configuration:
Automatic Output State | Disable
Off State Selection for Run Mode (OSSR) | Disable
Off State Selection for Idle Mode (OSSI) | Disable
Lock Configuration | Off
DeadTime Preload | Disable
Dead Time | 0
Asymmetrical DeadTime | Disable
Falling Dead Time | 0
Clear Input:
Clear Input Source | Disable
PWM Generation Channel 1 and 1N:
Mode | PWM mode 1
Pulse (16 bits value) | 0
Output compare preload | Enable
Fast Mode | Disable
CH Polarity | High
CHN Polarity | High
CH Idle State | Reset
CHN Idle State | Reset
PWM Generation Channel 2 and 2N:
Mode | PWM mode 1
Pulse (16 bits value) | 0
Output compare preload | Enable

Fast Mode | Disable
CH Polarity | High
CHN Polarity | High
CH Idle State | Reset
CHN Idle State | Reset
PWM Generation Channel 3 and 3N:
Mode | PWM mode 1
Pulse (16 bits value) | 0
Output compare preload | Enable
Fast Mode | Disable
CH Polarity | High
CHN Polarity | High
CH Idle State | Reset
CHN Idle State | Reset

### 3.8. TIM2

Channel3: PWM Generation CH3 Channel4: PWM Generation CH4
3.8.1. Parameter Settings:

Counter Settings:

Prescaler (PSC - 16 bits value) | 0
Counter Mode | Up
Dithering | Disable
Counter Period (AutoReload Register - 32 bits value ) | 4294967295
Internal Clock Division (CKD) | No Division
auto-reload preload | Disable
Trigger Output (TRGO) Parameters:
Master/Slave Mode (MSM bit) | Disable (Trigger input effect not delayed)
Trigger Event Selection TRGO | Reset (UG bit from TIMx_EGR)
Clear Input:
Clear Input Source | Disable
PWM Generation Channel 3:
Mode | PWM mode 1
Pulse (32 bits value) | 0
Output compare preload | Enable
Fast Mode | Disable
CH Polarity | High
PWM Generation Channel 4:

Mode | PWM mode 1
Pulse (32 bits value) | 0
Output compare preload | Enable
Fast Mode | Disable
CH Polarity | High

### 3.9. TIM8

Channel1: PWM Generation CH1
3.9.1. Parameter Settings:

Counter Settings:

Prescaler (PSC - 16 bits value) | 0
Counter Mode | Up
Dithering | Disable
Counter Period (AutoReload Register - 16 bits value ) | 65535
Internal Clock Division (CKD) | No Division
Repetition Counter (RCR - 16 bits value) | 0
auto-reload preload | Disable
Trigger Output (TRGO) Parameters:
Master/Slave Mode (MSM bit) | Disable (Trigger input effect not delayed)
Trigger Event Selection TRGO | Reset (UG bit from TIMx_EGR)
Trigger Event Selection TRGO2 | Reset (UG bit from TIMx_EGR)
Break And Dead Time management - BRK Configuration:
BRK State | Disable
BRK Polarity | High
BRK Filter (4 bits value) | 0
BRK Sources Configuration
- Digital Input | Disable
- COMP1 | Disable
- COMP2 | Disable
- COMP3 | Disable
- COMP4 | Disable
Break And Dead Time management - BRK2 Configuration:
BRK2 State | Disable
BRK2 Polarity | High
BRK2 Filter (4 bits value) | 0
BRK2 Sources Configuration
- Digital Input | Disable
- COMP1 | Disable
- COMP2 | Disable

- COMP3 | Disable
- COMP4 | Disable
Break And Dead Time management - Output Configuration:
Automatic Output State | Disable
Off State Selection for Run Mode (OSSR) | Disable
Off State Selection for Idle Mode (OSSI) | Disable
Lock Configuration | Off
Clear Input:
Clear Input Source | Disable
PWM Generation Channel 1:
Mode | PWM mode 1
Pulse (16 bits value) | 0
Output compare preload | Enable
Fast Mode | Disable
CH Polarity | High
CH Idle State | Reset

### 3.10. USART2

Mode: Asynchronous
3.10.1. Parameter Settings:

Basic Parameters:

Baud Rate | 115200
Word Length | 8 Bits (including Parity)
Parity | None
Stop Bits | 1
Advanced Parameters:
Data Direction | Receive and Transmit
Over Sampling | 16 Samples
Single Sample | Disable
ClockPrescaler | 1
Fifo Mode | Disable
Txfifo Threshold | 1 eighth full configuration
Rxfifo Threshold | 1 eighth full configuration
Advanced Features:
Auto Baudrate | Disable
TX Pin Active Level Inversion | Disable
RX Pin Active Level Inversion | Disable
Data Inversion | Disable
TX and RX Pins Swapping | Disable

Overrun | Enable
DMA on RX Error | Enable
MSB First | Disable

* User modified value

## 4. System Configuration

### 4.1. GPIO configuration

IP | Pin | Signal | GPIO mode | GPIO pull/up pull down | Max Speed | User Label
ADC1 | PA0 | ADC1_IN1 | Analog mode | No pull-up and no pull-down | n/a
| PA1 | ADC1_IN2 | Analog mode | No pull-up and no pull-down | n/a
FDCAN1 | PA11 | FDCAN1_RX | Alternate Function Push Pull | No pull-up and no pull-down | Low
| PA12 | FDCAN1_TX | Alternate Function Push Pull | No pull-up and no pull-down | Low
I2C1 | PA15 | I2C1_SCL | Alternate Function Open Drain | No pull-up and no pull-down | Low
| PB7 | I2C1_SDA | Alternate Function Open Drain | No pull-up and no pull-down | Low
SPI1 | PA5 | SPI1_SCK | Alternate Function Push Pull | No pull-up and no pull-down | Low
| PA6 | SPI1_MISO | Alternate Function Push Pull | No pull-up and no pull-down | Low
| PB5 | SPI1_MOSI | Alternate Function Push Pull | No pull-up and no pull-down | Low
SYS | PA13 | SYS_JTMS-SWDIO | n/a | n/a | n/a
| PA14 | SYS_JTCK-SWCLK | n/a | n/a | n/a
TIM1 | PF0-OSC_IN | TIM1_CH3N | Alternate Function Push Pull | No pull-up and no pull-down | Low
| PA7 | TIM1_CH1N | Alternate Function Push Pull | No pull-up and no pull-down | Low
| PB0 | TIM1_CH2N | Alternate Function Push Pull | No pull-up and no pull-down | Low
| PA8 | TIM1_CH1 | Alternate Function Push Pull | No pull-up and no pull-down | Low
| PA9 | TIM1_CH2 | Alternate Function Push Pull | No pull-up and no pull-down | Low
| PA10 | TIM1_CH3 | Alternate Function Push Pull | No pull-up and no pull-down | Low
TIM2 | PA2 | TIM2_CH3 | Alternate Function Push Pull | No pull-up and no pull-down | Low | RGB_R
| PA3 | TIM2_CH4 | Alternate Function Push Pull | No pull-up and no pull-down | Low | RGB_G
TIM8 | PB6 | TIM8_CH1 | Alternate Function Push Pull | No pull-up and no pull-down | Low | RGB_B
USART2 | PB3 | USART2_TX | Alternate Function Push Pull | No pull-up and no pull-down | Low
| PB4 | USART2_RX | Alternate Function Push Pull | No pull-up and no pull-down | Low
GPIO | PF1-OSC_OUT | GPIO_Output | Output Push Pull | No pull-up and no pull-down | Low | LED1
| PG10-NRST | GPIO_Input | Input mode | No pull-up and no pull-down | n/a
| PA4 | GPIO_Output | Output Push Pull | No pull-up and no pull-down | Low | LED2
| PB8-BOOT0 | GPIO_Input | Input mode | No pull-up and no pull-down | n/a | BOOT0

### 4.2. DMA configuration

DMA request | Stream | Direction | Priority
ADC1 | DMA1_Channel2 | Peripheral To Memory | Low
USART2_RX | DMA1_Channel1 | Peripheral To Memory | Low

ADC1: DMA1_Channel2 DMA request Settings:

Mode: | Circular *
Peripheral Increment: | Disable
Memory Increment: | Enable *
Peripheral Data Width: | Half Word
Memory Data Width: | Half Word

USART2_RX: DMA1_Channel1 DMA request Settings:

Mode: | Normal
Peripheral Increment: | Disable
Memory Increment: | Enable *
Peripheral Data Width: | Byte
Memory Data Width: | Byte

### 4.3. NVIC configuration

4.3.1. NVIC
Interrupt Table | Enable | Preenmption Priority | SubPriority
Non maskable interrupt | true | 0 | 0
Hard fault interrupt | true | 0 | 0
Memory management fault | true | 0 | 0
Prefetch fault, memory access fault | true | 0 | 0
Undefined instruction or illegal state | true | 0 | 0
System service call via SWI instruction | true | 0 | 0
Debug monitor | true | 0 | 0
Pendable request for system service | true | 0 | 0
System tick timer | true | 15 | 0
DMA1 channel1 global interrupt | true | 0 | 0
DMA1 channel2 global interrupt | true | 0 | 0
ADC1 and ADC2 global interrupt | true | 0 | 0
USART2 global interrupt / USART2 wake-up interrupt through EXTI line 26 | true | 0 | 0
PVD/PVM1/PVM2/PVM3/PVM4 interrupts through EXTI lines 16/38/39/40/41 | unused
Flash global interrupt | unused
RCC global interrupt | unused
FDCAN1 interrupt 0 | unused
FDCAN1 interrupt 1 | unused
TIM1 break interrupt and TIM15 global interrupt | unused
TIM1 update interrupt and TIM16 global interrupt | unused
TIM1 trigger and commutation interrupts and TIM17 global interrupt | unused
TIM1 capture compare interrupt | unused
TIM2 global interrupt | unused
I2C1 event interrupt / I2C1 wake-up interrupt through EXTI line 23 | unused
I2C1 error interrupt | unused
SPI1 global interrupt | unused
TIM8 break interrupt | unused
TIM8 update interrupt | unused
TIM8 trigger and commutation interrupts | unused
TIM8 capture compare interrupt | unused
FPU global interrupt | unused
4.3.2. NVIC Code generation

Enabled interrupt Table | Select for init sequence ordering | Generate IRQ handler | Call HAL handler
Non maskable interrupt | false | true | false
Hard fault interrupt | false | true | false
Memory management fault | false | true | false
Prefetch fault, memory access fault | false | true | false
Undefined instruction or illegal state | false | true | false
System service call via SWI instruction | false | true | false
Debug monitor | false | true | false
Pendable request for system service | false | true | false
System tick timer | false | true | true
DMA1 channel1 global interrupt | false | true | true
DMA1 channel2 global interrupt | false | true | true
ADC1 and ADC2 global interrupt | false | true | true
USART2 global interrupt / USART2 wake-up interrupt through EXTI line 26 | false | true | true

* User modified value

## 5. System Views

5.1. Category view
5.1.1. Current

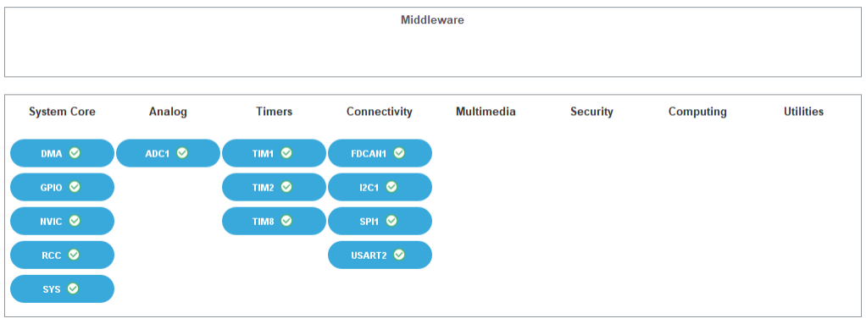
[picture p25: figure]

## 6. Docs & Resources

Type | Link
BSDL files | https://www.st.com/resource/en/bsdl_model/stm32g4_bsdl.zip
IBIS models | https://www.st.com/resource/en/ibis_model/stm32g4_ibis.zip
System View Description | https://www.st.com/resource/en/svd/stm32g4_svd.zip
Presentations | https://www.st.com/resource/en/product_presentation/stm32-stm8_embedded_software_solutions.pdf
Presentations | https://www.st.com/resource/en/product_presentation/stm32_eval-tools_portfolio.pdf
Presentations | https://www.st.com/resource/en/product_presentation/stm32_stm8_functi onal-safety-packages.pdf
Presentations | https://www.st.com/resource/en/product_presentation/stm32-usb-c-pd-solutions-presentation.pdf
Presentations | https://www.st.com/resource/en/product_presentation/stm32-stm8_software_development_tools.pdf
Presentations | https://www.st.com/resource/en/product_presentation/microcontrollers-stm32-family-overview.pdf
Presentations | https://www.st.com/resource/en/product_presentation/microcontrollers-stm32g4-series-product-overview.pdf
Brochures | https://www.st.com/resource/en/brochure/products-and-solutions-for-plcs-and-smart-i-os.pdf
Flyers | https://www.st.com/resource/en/flyer/flstm32g4.pdf
Flyers | https://www.st.com/resource/en/flyer/flstm32nucleo.pdf
Flyers | https://www.st.com/resource/en/flyer/flstm32trust.pdf
Flyers | https://www.st.com/resource/en/flyer/fldpstpfc11120.pdf
Application Notes | https://www.st.com/resource/en/application_note/an1709-emc-design-guide-for-stm8-stm32-and-legacy-mcus-stmicroelectronics.pdf
Application Notes | https://www.st.com/resource/en/application_note/an2606-stm32-microcontroller-system-memory-boot-mode-stmicroelectronics.pdf
Application Notes | https://www.st.com/resource/en/application_note/an3126-audio-and-

| waveform-generation-using-the-dac-in-stm32-products-stmicroelectronics.pdf
Application Notes | https://www.st.com/resource/en/application_note/an3155-usart-protocol-used-in-the-stm32-bootloader-stmicroelectronics.pdf
Application Notes | https://www.st.com/resource/en/application_note/an3156-usb-dfu-protocol-used-in-the-stm32-bootloader-stmicroelectronics.pdf
Application Notes | https://www.st.com/resource/en/application_note/an4221-i2c-protocol-used-in-the-stm32-bootloader-stmicroelectronics.pdf
Application Notes | https://www.st.com/resource/en/application_note/an4232-getting-started-with-analog-comparators-for-stm32f3-series-and-stm32g4-series-devices-stmicroelectronics.pdf
Application Notes | https://www.st.com/resource/en/application_note/an4286-spi-protocol-used-in-the-stm32-bootloader-stmicroelectronics.pdf
Application Notes | https://www.st.com/resource/en/application_note/an4296-use-stm32f3stm32g4-ccm-sram-with-iar-embedded-workbench-keil-mdkarm-stmicroelectronics-stm32cubeide-and-other-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
Application Notes | https://www.st.com/resource/en/application_note/an4566-extending-the-dac-performance-of-stm32-microcontrollers-stmicroelectronics.pdf
Application Notes | https://www.st.com/resource/en/application_note/an4655-virtually-increasing-the-number-of-serial-communication-peripherals-in-stm32-applications-stmicroelectronics.p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
Application Notes | https://www.st.com/resource/en/application_note/an4750-handling-of-soft-errors-in-stm32-applications-stmicroelectronics.pdf
Application Notes | https://www.st.com/resource/en/application_note/an4776-generalpurpose-timer-cookbook-for-stm32-microcontrollers-stmicroelectronics.pdf
Application Notes | https://www.st.com/resource/en/application_note/an4803-highspeed-si-simulations-using-ibis-and-boardlevel-simulations-using-hyperlynx-si-on-stm32-mcus-and-mpus-stmic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
Application Notes | https://www.st.com/resource/en/application_note/an4989-stm32-microcontroller-debug-toolbox-stmicroelectronics.pdf
Application Notes | https://www.st.com/resource/en/application_note/an5027-interfacing-pdm-digital-microphones-using-stm32-mcus-and-mpus-stmicroelectronics.pdf

Application Notes | https://www.st.com/resource/en/application_note/an5093-getting-started-with-stm32g4-series--hardware-development-boards-stmicroelectronics.pdf
Application Notes | https://www.st.com/resource/en/application_note/an5306-operational-amplifier-opamp-usage-in-stm32g4-series-stmicroelectronics.pdf
Application Notes | https://www.st.com/resource/en/application_note/an5310-guideline-for-using-analog-features-of-stm32g4-series-versus-stm32f3-series-devices-stmicroelectronics.pdf
Application Notes | https://www.st.com/resource/en/application_note/an5315-stm32cube-firmware-examples-for-stm32g4-series-stmicroelectronics.pdf
Application Notes | https://www.st.com/resource/en/application_note/an5346-stm32g4-adc-use-tips-and-recommendations-stmicroelectronics.pdf
Application Notes | https://www.st.com/resource/en/application_note/an5094-migrating-between-stm32f334303-lines-and-stm32g431xxg474xxg491xx-microcontrollers-stmicroelectronics.pdf
Application Notes | https://www.st.com/resource/en/application_note/an5738-stm32g4-series-lifetime-estimates-stmicroelectronics.pdf
Application Notes | https://www.st.com/resource/en/application_note/an4899-stm32-microcontroller-gpio-hardware-settings-and-lowpower-consumption-stmicroelectronics.pdf
Application Notes | https://www.st.com/resource/en/application_note/an5612-esd-protection-of-stm32-mcus-and-mpus-stmicroelectronics.pdf
Application Notes | https://www.st.com/resource/en/application_note/an4991-how-to-wake-up-an-stm32-microcontroller-from-lowpower-mode-with-the-usart-or-the-lpuart-stmicroelectronics.pdf
Application Notes | https://www.st.com/resource/en/application_note/an4838-introduction-to-memory-protection-unit-management-on-stm32-mcus-stmicroelectronics.pdf
Application Notes | https://www.st.com/resource/en/application_note/an5325-how-to-use-the-cordic-to-perform-mathematical-functions-on-stm32-mcus-stmicroelectronics.pdf
Application Notes | https://www.st.com/resource/en/application_note/an5225-introduction-to-usb-typec-power-delivery-for-stm32-mcus-and-mpus-stmicroelectronics.pdf

Application Notes | https://www.st.com/resource/en/application_note/an4894-how-to-use-eeprom-emulation-on-stm32-mcus-stmicroelectronics.pdf
Application Notes | https://www.st.com/resource/en/application_note/an5537-how-to-use-adc-oversampling-techniques-to-improve-signaltonoise-ratio-on-stm32-mcus-stmicroelectronics.pdf
Application Notes | https://www.st.com/resource/en/application_note/an5036-guidelines-for-thermal-management-on-stm32-applications-stmicroelectronics.pdf
Application Notes | https://www.st.com/resource/en/application_note/an5405-how-to-use-fdcan-bootloader-protocol-on-stm32-mcus-stmicroelectronics.pdf
Application Notes | https://www.st.com/resource/en/application_note/an5978-introduction-to-mb1971-llc-hat-12-v-to-75-v1-a-for-f334-g474-nucleo-board-stmicroelectronics.pdf
Application Notes | https://www.st.com/resource/en/application_note/an5690-how-to-use-vrefbuf-peripheral-on-stm32-mcus-and-mpus-stmicroelectronics.pdf
Application Notes | https://www.st.com/resource/en/application_note/an4230-introduction-to-random-number-generation-validation-using-the-nist-statistical-test-suite-for-stm32-mcus-and-m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
Application Notes | https://www.st.com/resource/en/application_note/an2548-introduction-to-dma-controller-for-stm32-mcus-stmicroelectronics.pdf
Application Notes | https://www.st.com/resource/en/application_note/an4013-introduction-to-timers-for-stm32-mcus-stmicroelectronics.pdf
Application Notes | https://www.st.com/resource/en/application_note/an4277-how-to-use-pwm-shutdown-for-motor-control-and-digital-power-conversion-on-stm32-mcus-stmicroelectronics.pdf
Application Notes | https://www.st.com/resource/en/application_note/an4635-how-to-optimize-lpuart-power-consumption-on-stm32-mcus-stmicroelectronics.pdf
Application Notes | https://www.st.com/resource/en/application_note/an4759-introduction-to-using-the-hardware-realtime-clock-rtc-and-the-tamper-management-unit-tamp-with-stm32-mcus-stmi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
Application Notes | https://www.st.com/resource/en/application_note/an4908-getting-started-with-usart-automatic-baud-rater-detection-for-stm32-mcus-stmicroelectronics.pdf

Application Notes | https://www.st.com/resource/en/application_note/an5156-introduction-to-security-for-stm32-mcus-stmicroelectronics.pdf
Application Notes | https://www.st.com/resource/en/application_note/an5224-introduction-to-dmamux-for-stm32-mcus-stmicroelectronics.pdf
Application Notes | https://www.st.com/resource/en/application_note/an5543-guidelines-for-enhanced-spi-communication-on-stm32-mcus-and-mpus-stmicroelectronics.pdf
Application Notes | https://www.st.com/resource/en/application_note/an5348-introduction-to-fdcan-peripherals-for-stm32-mcus-stmicroelectronics.pdf
Application Notes | https://www.st.com/resource/en/application_note/cd00211314-how-to-optimize-the-adc-accuracy-in-the-stm32-mcus-stmicroelectronics.pdf
Application Notes | https://www.st.com/resource/en/application_note/an2639-soldering-recommendations-and-package-information-for-leadfree-ecopack2-mcus-and-mpus-stmicroelectronics.pdf
Application Notes for related Tools & Software | https://www.st.com/resource/en/application_note/an4435-guidelines-for-obtaining-ulcsaiec-607301603351-class-b-certification-in-any-stm32-application-stmicroelectroni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
Application Notes for related Tools & Software | https://www.st.com/resource/en/application_note/an4657-stm32-inapplication-programming-iap-using-the-usart-stmicroelectronics.pdf
Application Notes for related Tools & Software | https://www.st.com/resource/en/application_note/an4841-digital-signal-processing-for-stm32-microcontrollers-using-cmsis-stmicroelectronics.pdf
Application Notes for related Tools & Software | https://www.st.com/resource/en/application_note/an5056-integration-guide-for-the-xcubesbsfu-stm32cube-expansion-package-stmicroelectronics.pdf
Application Notes for related Tools & Software | https://www.st.com/resource/en/application_note/an5305-digital-filter-implementation-with-the-fmac-using-stm32cubeg4-mcu-package-stmicroelectronics.pdf
Application Notes for related Tools & Software | https://www.st.com/resource/en/application_note/an5315-stm32cube-firmware-examples-for-stm32g4-series-stmicroelectronics.pdf

Application Notes
for related Tools

https://www.st.com/resource/en/application_note/an5345-highbrightnessrgb-led-control-using-the-bg474edpow1-discovery-kit-

& Software | stmicroelectronics.pdf
Application Notes for related Tools & Software | https://www.st.com/resource/en/application_note/an5360-getting-started-with-projects-based-on-the-stm32mp1-series-in-stm32cubeide-stmicroelectronics.pdf
Application Notes for related Tools & Software | https://www.st.com/resource/en/application_note/an5361-getting-started-with-projects-based-on-dualcore-stm32h7-microcontrollers-in-stm32cubeide-stmicroelectronics.pd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
Application Notes for related Tools & Software | https://www.st.com/resource/en/application_note/an5394-getting-started-with-projects-based-on-the-stm32l5-series-in-stm32cubeide-stmicroelectronics.pdf
Application Notes for related Tools & Software | https://www.st.com/resource/en/application_note/an5418-how-to-build-a-simple-usbpd-sink-application-with-stm32cubemx-stmicroelectronics.pdf
Application Notes for related Tools & Software | https://www.st.com/resource/en/application_note/an5426-migrating-graphics-middleware-projects-from-stm32cubemx-540-to-stm32cubemx-550-stmicroelectronics.pdf
Application Notes for related Tools & Software | https://www.st.com/resource/en/application_note/an5464-position-control-of-a-threephase-permanent-magnet-motor-using-xcubemcsdk-or-xcubemcsdkful-stmicroelectronics.p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
Application Notes for related Tools & Software | https://www.st.com/resource/en/application_note/an5564-getting-started-with-projects-based-on-dualcore-stm32wl-microcontrollers-in-stm32cubeide-stmicroelectronics.pd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
Application Notes for related Tools & Software | https://www.st.com/resource/en/application_note/an5698-adapting-the-xcubestl-functional-safety-package-for-stm32-iec-61508-compliant-to-other-safety-standards-stmicr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
Application Notes for related Tools & Software | https://www.st.com/resource/en/application_note/an5731-stm32cubemx-and-stm32cubeide-threadsafe-solution-stmicroelectronics.pdf
Application Notes for related Tools & Software | https://www.st.com/resource/en/application_note/an5785-boost-voltage-mode-on-bg474edpow1-discovery-kit-stmicroelectronics.pdf
Application Notes for related Tools & Software | https://www.st.com/resource/en/application_note/an5788-stm32-digital-power-pid-and-iir-filters-for-smps-control-design-and-comparison-on-bg414edpow1-discovery-kit-st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

Application Notes for related Tools & Software | https://www.st.com/resource/en/application_note/an4502-stm32-smbuspmbus-expansion-package-for-stm32cube-stmicroelectronics.pdf
Application Notes for related Tools & Software | https://www.st.com/resource/en/application_note/an5952-how-to-use-cmake-in-stm32cubeide-stmicroelectronics.pdf
Application Notes for related Tools & Software | https://www.st.com/resource/en/application_note/an4635-how-to-optimize-lpuart-power-consumption-on-stm32-mcus-stmicroelectronics.pdf
Application Notes for related Tools & Software | https://www.st.com/resource/en/application_note/an5054-how-to-perform-secure-programming-using-stm32cubeprogrammer-stmicroelectronics.pdf
Application Notes for related Tools & Software | https://www.st.com/resource/en/application_note/an5496-guidelines-for-the-buck-voltage-mode-on-the-bg474edpow1-discovery-kit-stmicroelectronics.pdf
Application Notes for related Tools & Software | https://www.st.com/resource/en/application_note/an5497-introduction-to-the-buck-current-mode-with-the-bg474edpow1-discovery-kit-stmicroelectronics.pdf
Application Notes for related Tools & Software | https://www.st.com/resource/en/application_note/an6179-how-to-integrate-the-stl-firmware-into-a-time-critical-user-application-stmicroelectronics.pdf
Errata Sheets | https://www.st.com/resource/en/errata_sheet/es0431-stm32g431xx441xx-device-errata-stmicroelectronics.pdf
Datasheet | https://www.st.com/resource/en/datasheet/dm00507199.pdf
Programming Manuals | https://www.st.com/resource/en/programming_manual/pm0214-stm32-cortexm4-mcus-and-mpus-programming-manual-stmicroelectronics.pdf
Reference Manuals | https://www.st.com/resource/en/reference_manual/rm0440-stm32g4-series-advanced-armbased-32bit-mcus-stmicroelectronics.pdf
Technical Notes & Articles | https://www.st.com/resource/en/technical_note/tn1163-description-of-wlcsp-for-microcontrollers-and-recommendations-for-its-use-stmicroelectronics.pdf
Technical Notes & Articles | https://www.st.com/resource/en/technical_note/tn1204-tape-and-reel-shipping-media-for-stm32-microcontrollers-in-bga-packages-stmicroelectronics.pdf

Technical Notes & Articles | https://www.st.com/resource/en/technical_note/tn1205-tape-and-reel-shipping-media-for-stm8-and-stm32-microcontrollers-in-fpn-packages-stmicroelectronics.pdf
Technical Notes & Articles | https://www.st.com/resource/en/technical_note/tn1206-tape-and-reel-shipping-media-for-stm8-and-stm32-microcontrollers-in-qfp-packages-stmicroelectronics.pdf
Technical Notes & Articles | https://www.st.com/resource/en/technical_note/tn1207-tape-and-reel-shipping-media-for-stm8-and-stm32-microcontrollers-in-so-packages-stmicroelectronics.pdf
Technical Notes & Articles | https://www.st.com/resource/en/technical_note/tn1208-tape-and-reel-shipping-media-for-stm8-and-stm32-microcontrollers-in-tssop-and-ssop-packages-stmicroelectronics.p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
Technical Notes & Articles | https://www.st.com/resource/en/technical_note/tn1433-reference-device-marking-schematics-for-stm32-microcontrollers-and-microprocessors-stmicroelectronics.pdf
Technical Notes & Articles | https://www.st.com/resource/en/technical_note/tn1489-security-bulletin-tn1489stpsirt-physical-attacks-on-stm32-and-stm32cube-firmware-stmicroelectronics.pdf
User Manuals | https://www.st.com/resource/en/user_manual/um3167-stm32g4-series-ulcsaiec-607301603351-selftest-library-user-guide-stmicroelectronics.pdf

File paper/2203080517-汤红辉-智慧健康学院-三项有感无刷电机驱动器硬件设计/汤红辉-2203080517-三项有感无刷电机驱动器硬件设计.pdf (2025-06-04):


I

# 全日制学生毕业设计

# 任务书

学 | 院 | 智慧健康学院
专业班级 | 嵌入式技术应用
学生姓名 | 汤红辉 | 学号 | 2203080517
指导教师 | 刘祥明 王玺伟 | 职称 讲师 工程师
题 | 目 | 三项有感无刷电机驱动器硬件设计

2024 年 6 月 28 日

II

毕业设计任务：
设计内容：1．掌握相关理论基础,深入学习和理解三项有感无刷电机（BLDC） 的工作原理、控制策略及其应用场景。2．进行电机驱动电路的设计，包括但不 限于功率电子元件的选择、电路拓扑结构的确定等。使用专业软件（如 Altium Designer, PSpice 等）进行电路仿真以验证设计的有效性。3. 基于设计方案制作 实际的硬件原型，包括 PCB 板的设计与制作、元器件的焊接及调试。4.将硬件 部分与控制算法结合，完成整个驱动系统的组装，并进行功能性和性能测试， 确保其满足预期的技术指标。
设计指标：确保驱动器能够稳定驱动三项有感无刷电机，达到预定的速度和扭 矩输出。实现对电机状态的实时监控与反馈调节，保证运行的安全性和稳定性。 完成一套完整的硬件设计方案，包括电路图、PCB 设计文件以及相关的技术文 档。提交一份详尽的毕业设计论文，清晰阐述设计思路、实施步骤、实验结果 及其分析。
设计任务要求：
1．具备扎实的电力电子学、自动控制原理等相关专业知识。2．能够熟练使用 电路设计软件进行电路设计和仿真。3. 具有一定的动手能力，能够独立完成硬 件的制作与调试工作。4. 在指导教师的帮助下，解决设计过程中遇到的各种问 题，按时完成各阶段的任务。
主要参考文献：
[1] 顾伟康.一体化无刷直流电机控制研究和实现[D].东南大学,2015.
[2] 黄龙亮,胡鹏飞,陈玉洁,等.基于 ARM 的无刷直流电机容错控制系统研究[J]. 自动化应用,2024,65(12):103-104+108.DOI:10.19769/j.zdhy.2024.12.033.
[3] 王飞.BLDC 驱动电路设计及应用[D].西安电子科技大学,2017.
[4] 谭加尼.基于 STM32 的无刷直流电机控制器研制[D].武汉工程大 学,2020.DOI:10.27727/d.cnki.gwhxc.2020.000290.
[5] 敬心灵.基于 STM32 的无刷直流电机矢量控制系统研究[D].常州大 学,2022.DOI:10.27739/d.cnki.gjsgy.2022.000412.
[6] 马鸿德.BLDC 电机控制器的研究与设计[D].中国海洋大学,2015.
[7] 王聪.基于 STM32 的无刷直流电机控制系统研究[J].微处理 机,2022,43(02):11-15.
[8] 赵国清,武涵.基于 STM32 的无感无刷直流电机控制系统设计[J].自动化应 用,2024,65(05):142-148+152.DOI:10.19769/j.zdhy.2024.05.042.
[9] 方思鹏.无刷直流电机高性能驱动电路的设计与实现[D].电子科技大 学,2023.DOI:10.27005/d.cnki.gdzku.2023.003895.
[10] 张平稳.高速无刷直流电机控制系统硬件电路设计[J].自动化应 用,2019,(09):44-45+48.DOI:10.19769/j.zdhy.2019.09.017.

进度计划：

2024 年 9 月 16 日至 2024 年 10 月 19 日：进行相关文献查找和阅读，了解 三项有感无刷电机的工作原理及其驱动器设计的基本概念，并完成开题报告及

III

开题答辩。
2024 年 10 月 20 日至 2024 年 12 月 21 日：深入学习电机控制理论、电路 设计基础以及相关电子元件的选择。开始进行初步的硬件设计工作，包括电路 图绘制和元件选型。
2024 年 12 月 22 日至 2025 年 2 月 21 日：完成详细的硬件设计方案，包括 PCB 设计、元器件采购等。着手制作原型并进行初步测试，确保各部分功能正 常。
2025 年 2 月 22 日至 2025 年 3 月 21 日：进行全面的系统集成和测试，优 化驱动器性能。撰写毕业设计论文初稿，并进行查重。
2025 年 3 月 22 日至 2025 年 4 月 24 日：进一步完善毕业设计论文，根据 实验结果调整和优化设计。
2025 年 4 月 25 日至 2025 年 5 月 8 日：准备答辩材料，完成毕业设计答辩。
任务起止日期： | 2024 年 10 月 19 日至 | 2025 | 年 5 月 8 日

指导教师签字：

IV

# 全日制学生毕业设计

# 开题报告

题 | 目 | 三项有感无刷电机驱动器硬件设计
学 | 院 | 智慧健康学院
专业班级 | 嵌入式 2202
学生姓名 | 汤红辉 | 学号 2203080517
指导教师 刘祥明 王玺伟 | 职称 高级实验师

2024 年 10 月 8 日

V

## 毕业设计（论文）开题报告

1.课题目的及意义，国内外研究现状分析

目的：
本项目旨在设计并实现一个用于三项有感无刷电机的高效、可靠的驱动器硬 件。通过这一设计，期望能够优化电机控制性能，提高能效比，并为工业应用提 供一种新的解决方案。
意义：

### 1. 提升电机运行效率和可靠性。

### 2. 推动电机控制技术的发展，特别是在高效节能领域。

### 3. 应对现代工业中对高性能电机驱动器的需求，促进相关产业的技术升级。

国内研究现状：
在中国，随着工业自动化水平的不断提高和对能源效率的关注增加，对于高 性能电机驱动系统的需求日益增长。三项有感无刷电机（BLDC）因其高效能、 长寿命以及良好的控制性能，在众多领域得到了广泛应用，如家用电器、电动车、 工业自动化等。然而，相较于国际先进水平，国内在三项有感无刷电机驱动器的 设计与制造方面仍存在一定的差距。虽然国内已有不少企业在进行三项有感无刷 电机及其驱动器的研发和生产，但在高端应用领域，如航空航天、精密机床等， 其电机控制精度和稳定性仍有待提高。当前国内市场上的电机驱动产品主要集中 在中低端市场，而高端市场的份额则被国外品牌占据。这表明国内企业需要进一 步提升技术水平以满足更高质量标准的要求。近年来，中国政府出台了一系列鼓 励创新和技术升级的政策措施，旨在推动包括电机驱动在内的制造业向更高附加 值方向转型。这些政策为电机驱动技术的发展提供了有力的支持。 国外研究现状：
在国外，尤其是欧美发达国家和地区，三项有感无刷电机驱动器的研究和应 用已经达到了较高的水平，并广泛应用于多个高科技领域。国外研究机构和企业 在三项有感无刷电机驱动器的技术创新方面取得了显著进展。例如，采用先进的 控制算法（如矢量控制、直接转矩控制等）提高了电机的运行效率和动态响应速 度；利用新材料（如碳化硅 SiC 功率器件）提升了驱动器的工作频率和能量转换 效率。在高端制造、新能源汽车、医疗器械等领域，三项有感无刷电机驱动器的 应用非常普遍。这些应用场景要求极高的可靠性、精确度以及适应复杂环境的能 力，国外的产品往往能够更好地满足这些需求。为了降低开发成本并加快产品上 市时间，许多国外制造商倾向于采用标准化和模块化设计理念。这种方法不仅有

VI

助于提高产品的兼容性和可维护性，还能促进整个行业的健康发展。 综上所述，尽管国内外在三项有感无刷电机驱动器的研究和发展方面均取得 了一定的成绩，但总体来看，国外在技术创新、高端应用以及标准化设计等方面 仍然领先于国内。因此，如何吸收借鉴国外先进技术经验的同时结合本国实际情 况进行自主创新，是未来中国电机驱动行业面临的重要课题。通过持续的技术研 发投入和人才培养，有望缩小与国际先进水平之间的差距，并在全球竞争中占据 一席之地。
2.本课题的任务、重点内容、实现途径
课题任务：
设计并实现一款三项有感无刷电机驱动器，满足特定应用场景下的性能要 求。完成从理论分析到实际硬件实现的全过程，包括电路设计、PCB 制作、元件 选型及系统集成测试。
重点内容：
在设计与开电机驱动时，需要重点关注以下几个方面：

### 1. 需求分析：明确驱动器的功能需求、性能指标以及用户需求。

### 2. 系统设计：包括电路设计、元器件选择、PCB 布局等。

### 3. 数据处理与控制算法：开发适合的控制策略，保证电机高效稳定运行。

实现途径：

### 1. 使用 Altium Designer 或 PSpice 等工具进行电路设计与仿真

### 2. 进行详细的硬件原型设计与制作，并通过实验验证其性能。

硬件系统测试：对系统进行全面的测试，包括功能测试、性能测试和安全测试等， 确保系统的稳定性和安全性。
3.课题可行性分析

VII

三项有感无刷电机驱动器硬件设计项目的技术可行性主要基于以下几个方面：

### 1. 现有的技术基础：当前，电力电子技术和自动控制理论已经非常成熟，为本

项目的实施提供了坚实的技术支持。例如，矢量控制和直接转矩控制等先进 的电机控制算法已经被广泛应用于无刷直流电机的驱动系统中。此外，现代 微控制器（MCU）和数字信号处理器（DSP）的发展也为电机控制系统的实现 提供了强大的计算能力和丰富的接口资源。

### 2. 软件工具的支持：Altium Designer、PSpice 等电路设计和仿真软件能够有

效地辅助进行电路设计与验证。这些工具不仅简化了设计流程，还提高了设 计的准确性和可靠性。通过这些软件工具的应用，可以对电路设计进行详细 的仿真测试，提前发现并解决潜在的问题。

### 3. 元器件的选择：随着半导体制造工艺的进步，功率 MOSFET、IGBT 等高效能

电子元件的成本不断下降，性能不断提升，这为三项有感无刷电机驱动器的 设计提供了更多选择。同时，市场上也出现了许多专门为电机控制设计的专 用集成电路（ASIC），这些都极大地促进了电机驱动器的小型化、高效化发 展。

### 4. 成本效益分析：虽然高性能的电机驱动器在研发初期可能需要较高的投入，

但考虑到其长期运行中的节能效果以及维护成本的降低，整体经济效益显 著。特别是对于工业自动化领域，高效的电机驱动系统不仅能提高生产效率， 还能大幅减少能源消耗，从而带来可观的经济回报。

### 5. 市场需求潜力：随着全球范围内对节能减排要求的不断提高，市场对高效能

电机驱动器的需求日益增长。尤其是在新能源汽车、智能家居等领域，三项 有感无刷电机驱动器的应用前景广阔。因此，开发一款性能优异的产品具有 广阔的市场空间和良好的商业价值。
4.完成本课题所需的工作条件（如工具书、计算机、实验、调研等）及解决办法

学生宿舍管理系统的设计与实现课题所需的工作条件包括以下几个方面：

### 1. 工具书和文献：需要查阅与电力电子、自动控制理论、三项有感无刷电机及

其驱动技术相关的专业书籍和技术文档。获取最新的研究成果和技术进展， 以保证设计方案的先进性和科学性。
解决办法：利用学校图书馆或在线数据库查找并借阅相关领域的权威书籍和 学术论文。参考官方文档和技术手册，以及所选用元器件的技术说明书。加 入相关的技术论坛和社区，以便及时获取行业动态，并与其他研究者交流心 得。

### 2. 计算机及软件环境：需要一台或多台配置较高的计算机用于电路设计、仿真、

PCB 制作以及后续的数据处理和分析工作。
解决办法：根据项目需求，选择适合的计算机配置，确保其能够满足高性能

VIII

计算的要求。可以考虑使用学校的实验室资源或者自购高性能计算机。下载 并安装所需的软件工具，确保所有工具均为最新版本，以获得最佳的功能支 持和技术支持。对于一些昂贵的专业软件，可以通过教育许可的方式获取免 费或低成本的使用权，许多软件厂商为学生提供特别优惠。

### 3. 实验条件：需要在一个配备齐全的实验室环境中进行硬件原型的制作和测

试。这包括焊接设备、测量仪器（如示波器、万用表等）、电源供应器等。 准备足够的测试数据，包括电机参数、运行状态记录等，以验证系统的正确 性和稳定性。
解决办法：与学校实验室管理部门协商，争取获得实验室资源的使用权，特 别是那些专门用于电子电路设计和测试的实验室。构建详细的测试计划，准 备充分的测试数据和场景，确保每一个功能模块都能得到全面而严格的测 试。

### 4. 调研：需要对现有的三项有感无刷电机驱动系统进行深入调研，了解其功能

特点、优缺点以及用户反馈。收集目标应用领域的需求信息，明确最终用户 的实际需求，为系统设计提供依据。
解决办法：通过问卷调查、访谈等方式直接从潜在用户那里收集需求信息。 同时，也可以参考已有的市场研究报告和技术白皮书。参加行业会议、研讨 会或展会，了解最新的产品趋势和技术发展动态。这不仅有助于获取第一手 资料，还能建立有价值的行业联系。分析竞争对手的产品，找出它们的优势 和不足之处，从而为自己的设计提供改进方向。
5.工作思路及方案分析

为了确保《三项有感无刷电机驱动器硬件设计》项目的顺利进行，以下是详细的 工作思路及各阶段的方案分析：

### 1. 需求分析:明确项目的目标，包括提高电机控制精度、增强系统稳定性、优化

能效等。通过问卷调查、访谈等方式收集来自潜在用户或相关领域的反馈信 息，了解他们的具体需求。针对不同用户群体（如研发人员、维护人员和最 终用户）的需求进行分析。研究市场上现有的同类产品，分析其功能特点、 优缺点以及用户反馈，为本项目提供参考。整理调研结果，形成详细的需求 文档，涵盖功能需求、性能需求、安全需求等方面，并明确优先级。在初步 设计完成后，制作一个简易原型，进行初步测试以验证基本功能是否满足需 求。

### 2. 系统设计:定义系统的整体架构，包括硬件部分（电路拓扑结构、元器件选

型）、软件部分（控制算法的选择）以及人机交互界面的设计，考虑到电机 驱动器的安全性要求，需加入必要的保护机制，如过流保护、温度监控等。

IX

编写详细的系统设计文档，包括 ER 图、流程图、电路原理图、PCB 布局图 等，确保设计的每个细节都经过充分考虑。使用 Altium Designer、PSpice 等 工具进行电路仿真，验证设计方案的可行性和有效性。对于复杂的控制系统， 可以利用 MATLAB/Simulink 进行系统级仿真。

### 3. 系统实现：根据设计方案制作实际的硬件原型，包括 PCB 设计、元器件采购

及焊接。确保所有元件的质量符合标准，并按照设计图纸精确组装。如果涉 及到嵌入式软件开发，则需编写相应的控制程序，并进行调试。选择合适的 编程语言和开发环境（如 C/C++、Keil、IAR 等）。将硬件和软件部分结合 起来进行全面的系统集成测试，确保各模块能够协同工作，达到预期的功能 和性能指标。采用模块化设计方法，提高代码复用性和可维护性。每个功能 模块独立开发和测试，最后集成到整个系统中。利用 Eclipse 等集成开发环 境（IDE）提供的调试工具，方便进行代码调试，快速定位并解决问题。

### 4. 测试：包括测试范围、方法和标准，编写全面的测试用例，覆盖所有功能点

和边界条件。按照预定的测试计划执行单元测试、集成测试和系统测试，记 录并修复发现的问题。基于测试结果，对系统进行必要的性能优化，确保其 满足预期的技术指标。准备一个模拟的或真实的测试环境，包括所需的硬件 设备、软件配置等，确保测试环境尽可能接近实际应用场景。利用自动化测 试工具（如 LabVIEW, TestStand）来加速测试过程，提高测试效率和准确性。 通过故意引入故障（如电源波动、信号干扰），测试系统的鲁棒性和自我恢 复能力。
在以上工作思路的基础上，可以制定以下方案分析：

### 1. 需求方案分析：通过问卷调查和面对面访谈的方式收集来自潜在用户（如研

发人员、维护人员）及领域专家的需求反馈。

### 2. 系统设计方案分析：使用 Altium Designer 或 PSpice 等专业软件进行电路设

计与仿真，这些工具提供了直观的图形界面，使得电路设计和调试更加便捷。 采用模块化设计理念，将整个系统分解为多个独立但相互关联的功能模块， 便于后续的开发、测试和维护。根据性能要求选择合适的电子元件，考虑成 本效益的同时也要保证系统的稳定性和可靠性。

### 3. 系统实现方案分析：虽然原始内容提到 Java 语言，但对于本项目而言，更适

合选用 C/C++或其他适用于嵌入式系统的编程语言进行控制程序的编写。采 用模块化开发方式，提高代码复用性和可维护性。每个模块应具有清晰的接 口定义和独立的功能实现。选择适合的集成开发环境（IDE），如 Keil 或 IAR， 它们提供了强大的调试工具，有助于快速定位和解决问题。

### 4. 测试方案分析：构建一个模拟的或真实的测试环境，包括必要的硬件设备和

X

软件配置。确保所有组件均按照设计规格正确安装和配置。对系统的各个功 能模块进行全面测试，包括但不限于电机启动/停止、速度控制、位置控制等 功能。特别关注关键性能指标，如响应时间、精度等。基于测试结果对系统 进行必要的调整和优化，确保其在各种工况下都能稳定运行，并达到预期的 技术指标。

6.时间安排及工作进度
为了确保《三项有感无刷电机驱动器硬件设计》项目的顺利推进，以下是详细 的时间安排和工作进度计划：
第 1 阶段：启动和需求分析（1-2 周）

### 1. 收集关于三项有感无刷电机及其驱动系统的技术资料，进行初步的市场调

研。

### 2. 通过问卷调查、访谈等方式收集潜在用户的需求，并分析类似系统的功能

特点。
第 2 阶段：系统设计（1-2 周）

### 1. 设计系统的总体架构，包括电路拓扑结构、元器件选型等。

### 2. 使用 Altium Designer 或 PSpice 等工具进行电路仿真，验证设计方案的可行

性。
第 3 阶段：系统开发（2-3 个月）

### 1. 根据设计方案制作实际的硬件原型，包括 PCB 板的设计与制作、元器件采

购及焊接。

### 2. 编写嵌入式控制程序（如使用 C/C++），并进行初步调试。

### 3. 将硬件部分与控制算法结合，完成整个驱动系统的组装。

第 4 阶段：系统测试（2-3 周）

### 1. 搭建全面的测试环境，包括所需的硬件设备、软件配置等。

### 2. 对系统的各项功能进行全面测试，记录并修复发现的问题。

第 5 阶段：课题总结阶段（1-2 周）

### 1. 根据测试反馈进一步完善系统设计和实现，解决所有发现的问题。

### 2. 继续撰写和完善毕业设计论文，确保内容详实、逻辑清晰。

### 3. 答辩准备：制作课题答辩 PPT，展示课题研究成果。

### 4. 准备答辩所需的材料，如课题总结报告、系统演示视频等。

XI

7.指导教师意见：（对本课题的深度、广度及工作量的意见、对设计结果的预 测，并明确是否可以开题）
该课题深入探讨了三项有感无刷电机驱动器的设计与实现，涵盖了从理论分 析到实际硬件实现的全过程。项目不仅要求学生掌握电力电子学和自动控制原理 等基础知识，还需要具备电路设计、PCB 制作、嵌入式编程以及系统集成测试的 能力。这种跨学科的知识整合有助于培养学生的综合能力，符合毕业设计的要求。 课题内容广泛，涉及多个领域，包括但不限于电路设计、元器件选型、控制 系统开发、性能优化等。此外，还要求学生对市场需求和技术发展趋势有一定的 了解，以便设计出既具创新性又实用的产品。这不仅拓宽了学生的知识面，也为 他们未来的职业发展打下了坚实的基础。
整个项目的任务量适中且合理分配。从需求分析、系统设计、硬件实现、软 件编写到系统测试，每个阶段都有明确的任务和时间节点。虽然项目涵盖的内容 较多，但通过合理的规划和有效的资源利用，是可以按时完成的。特别是考虑到 学生已经具备一定的基础知识和技术背景，完成该项目的工作量是可行的。

指导教师

2024 年 10 月 8 日

8.系部（教研室）审查意见

系主任（签字）

年 | 月 | 日


XII

# 全日制本（专）科学生毕业设计

题 | 目 | 三项有感无刷电机驱动器硬件设计
学 | 院 | 智慧健康学院
专业班级 | 嵌入式 2202 班
学生姓名 | 汤红辉 | 学号 | 2203080517
指导教师 刘祥明 王玺伟 职称 | 讲师 工程师
评阅教师 | 贺晓辉 | 职称 | 副教授

2024 年 12 月 12 日

XIII

## 毕业设计原创性声明

本人郑重声明：所呈交的毕业设计《三项有感无刷电机驱动器硬件设

计》，是本人在指导教师指导下，在重庆电子科技职业大学学习期间进行的

研究工作所取得的成果。据我所知，除文中已经标明引用的内容外，本论文

不包含任何其他个人或集体已经发表或撰写过的研究成果。本人完全意识

到本声明的法律结果由本人承担。

毕业设计作者：

2025 年 | 5 月 | 19 日


XIV

## 毕业设计（论文）使用授权声明

本人完全了解重庆电子科技职业大学有关收集、保留和使用本人所送

交的毕业设计（论文）的规定，即：学生在校期间毕业设计（论文）工作的

知识产权单位属重庆电子科技职业大学。学校有权保留并向国家有关部门

或机构送交毕业设计（论文）的复印件和电子版，允许论文被查阅和借阅，

可以公布论文的全部或部分内容，可以采用影印、缩印或扫描等复制手段保

存、汇编论文。保密的论文在解密后适用本声明。

论文涉密情况：

□ 不保密

□ 保密，保密期（起讫日期： | ）
作者签名： | 指导教师签名：
2025 年 | 5 月 | 19 日 | 2025 年 | 5 月 | 19 日

重庆电子科技职业大学毕业设计

1

摘 要

无刷直流电机（Brushless DC Motor, BLDCM）是一种寿命长、可靠性高且易于维护 的机电一体化产品[1]。无刷直流电机运行可靠、功率密度高、寿命长、效率高，其在结 构上去除了电刷和换向器，减少了电机的维护费用和因换向器而引起的电磁干扰[2]。无 刷直流电机被认为是 21 世纪最具有发展潜力和应用前景的电机[3]。无刷直流电机以电 子换相来代替机械换相，有效解决了传统有刷直流电机的不足[4]。近年来，全球智能化

制造和发展成为主要趋势之一，无刷直流电机的价值被逐渐认知，随着高效无刷直流电 机技术的不断发展，无刷直流电机的成本呈下降趋势，无刷直流电机被广泛应用在智能 化相关产品中[5]。

无刷直流电机（BLDC 电机）以其卓越的效能、长久的使用寿命和高度的可靠性， 在工业自动化、消费电子、医疗设备、汽车工程以及航空航天等多个领域获得了广泛应 用。随着现代科技日新月异的发展，对电机驱动系统的性能要求日益提升，尤其在效率、 控制精度以及响应速度方面设定了更高的标准。这促使 BLDC 电机不断演进，以满足各 行业对高性能驱动解决方案的需求。传统的有刷电机由于机械磨损问题，导致其使用寿 命有限并且维护成本较高，而 BLDC 电机通过采用电子换向技术有效地解决了这些问 题，因此成为现代高性能应用中的理想选择。传统的有刷直流电机的应用包括摩托车玩 具，家用电器和计算机外围设备。汽车制造商把直流电机应用于电动车窗，座位和其他 内饰设计，主要是因为它们的成本低，控制简单[6]。

为进一步挖掘无刷直流电机的应用潜力，通过对其结构及工作原理的研究，设计一 种基于 STM32F407 的无刷直流电机控制系统[7]。本研究旨在结合 STM32F407VET6 微

控制器、EG2133 驱动芯片和 AS5600 位置传感器的优势，设计一款高性能的三相有感 无刷电机驱动器。通过优化硬件设计和软件算法，提高驱动器的效率、可靠性和控制精 度，以满足日益增长的高性能电机驱动需求。具体而言，我们将深入研究如何利用 STM32F407VET6 的高级处理能力来实现复杂的控制算法，同时通过 EG2133 驱动芯片 确保功率输出的稳定性和安全性，并通过 AS5600 位置传感器提供精确的位置反馈，进 一步提升系统性能。此外，本研究还将探讨如何降低成本、简化设计复杂度，使所设计 的驱动器更易于在实际应用中推广使用。通过本研究，我们希望能够为行业提供一种更 加经济、高效且可靠的解决方案，从而促进 BLDC 电机驱动技术的进一步普及和发展。

关键词：STM32；BLDC；EG2133；AS5600；PCB。

2
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

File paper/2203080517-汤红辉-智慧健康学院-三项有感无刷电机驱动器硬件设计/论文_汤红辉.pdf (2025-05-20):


I

# 全日制学生毕业设计

# 任务书

学 | 院 | 智慧健康学院
专业班级 | 嵌入式技术应用
学生姓名 | 汤红辉 | 学号 | 2203080517
指导教师 | 刘祥明 王玺伟 | 职称 讲师 工程师
题 | 目 | 三项有感无刷电机驱动器硬件设计

2024 年 6 月 28 日

II

毕业设计任务：
设计内容：1．掌握相关理论基础,深入学习和理解三项有感无刷电机（BLDC） 的工作原理、控制策略及其应用场景。2．进行电机驱动电路的设计，包括但不 限于功率电子元件的选择、电路拓扑结构的确定等。使用专业软件（如 Altium Designer, PSpice 等）进行电路仿真以验证设计的有效性。3. 基于设计方案制作 实际的硬件原型，包括 PCB 板的设计与制作、元器件的焊接及调试。4.将硬件 部分与控制算法结合，完成整个驱动系统的组装，并进行功能性和性能测试， 确保其满足预期的技术指标。
设计指标：确保驱动器能够稳定驱动三项有感无刷电机，达到预定的速度和扭 矩输出。实现对电机状态的实时监控与反馈调节，保证运行的安全性和稳定性。 完成一套完整的硬件设计方案，包括电路图、PCB 设计文件以及相关的技术文 档。提交一份详尽的毕业设计论文，清晰阐述设计思路、实施步骤、实验结果 及其分析。
设计任务要求：
1．具备扎实的电力电子学、自动控制原理等相关专业知识。2．能够熟练使用 电路设计软件进行电路设计和仿真。3. 具有一定的动手能力，能够独立完成硬 件的制作与调试工作。4. 在指导教师的帮助下，解决设计过程中遇到的各种问 题，按时完成各阶段的任务。
主要参考文献：
[1] 顾伟康.一体化无刷直流电机控制研究和实现[D].东南大学,2015.
[2] 黄龙亮,胡鹏飞,陈玉洁,等.基于 ARM 的无刷直流电机容错控制系统研究[J]. 自动化应用,2024,65(12):103-104+108.DOI:10.19769/j.zdhy.2024.12.033.
[3] 王飞.BLDC 驱动电路设计及应用[D].西安电子科技大学,2017.
[4] 谭加尼.基于 STM32 的无刷直流电机控制器研制[D].武汉工程大 学,2020.DOI:10.27727/d.cnki.gwhxc.2020.000290.
[5] 敬心灵.基于 STM32 的无刷直流电机矢量控制系统研究[D].常州大 学,2022.DOI:10.27739/d.cnki.gjsgy.2022.000412.
[6] 马鸿德.BLDC 电机控制器的研究与设计[D].中国海洋大学,2015.
[7] 王聪.基于 STM32 的无刷直流电机控制系统研究[J].微处理 机,2022,43(02):11-15.
[8] 赵国清,武涵.基于 STM32 的无感无刷直流电机控制系统设计[J].自动化应 用,2024,65(05):142-148+152.DOI:10.19769/j.zdhy.2024.05.042.
[9] 方思鹏.无刷直流电机高性能驱动电路的设计与实现[D].电子科技大 学,2023.DOI:10.27005/d.cnki.gdzku.2023.003895.
[10] 张平稳.高速无刷直流电机控制系统硬件电路设计[J].自动化应 用,2019,(09):44-45+48.DOI:10.19769/j.zdhy.2019.09.017.
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

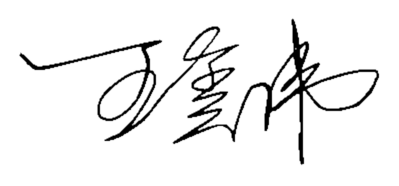
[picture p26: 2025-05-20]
paper/王玺伟电子签名.png

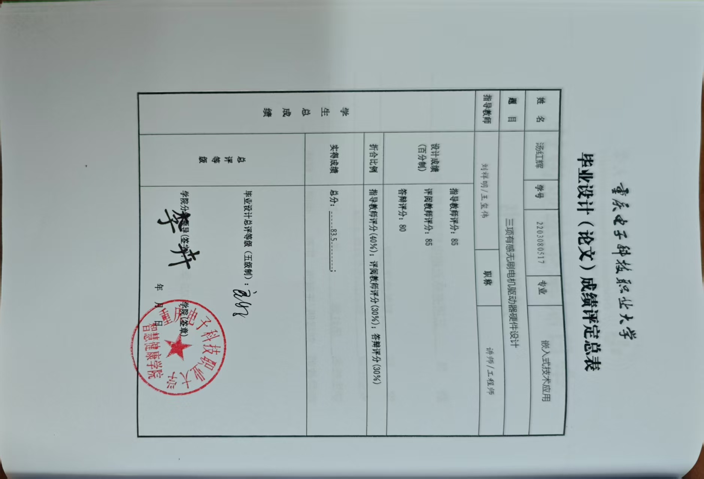
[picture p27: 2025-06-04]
paper/2203080517-汤红辉-智慧健康学院-三项有感无刷电机驱动器硬件设计/成绩评定表.jpg

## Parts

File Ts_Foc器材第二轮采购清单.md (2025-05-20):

# Ts_Foc器材第二轮采购清单

1. 5pinGH1.25段子线材以及端子
2. 3Pin电机直插母头
3. Gh1.25同向端子线

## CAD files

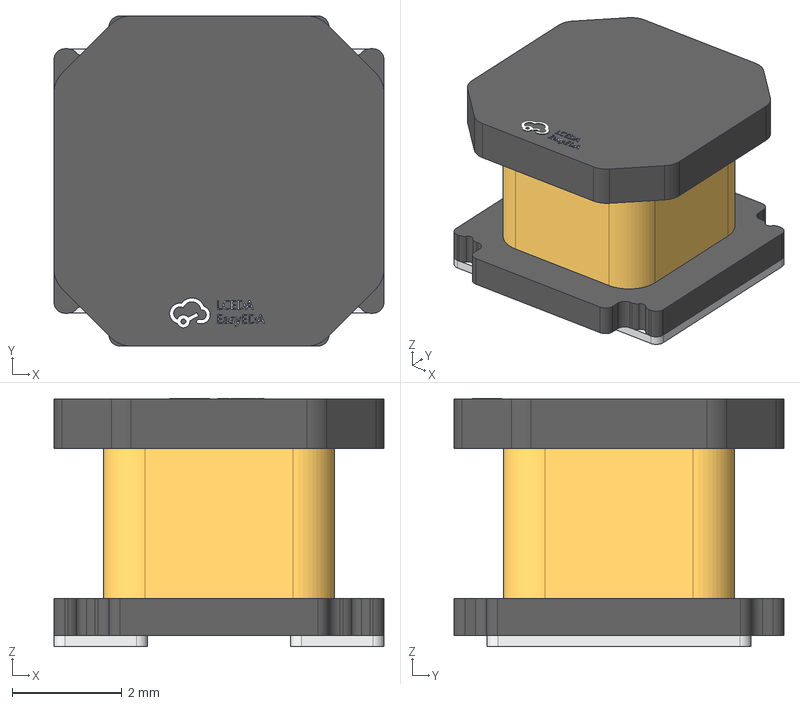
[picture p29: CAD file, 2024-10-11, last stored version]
CawFOC/caw-drive-master/PCB/3DModel/VLS6045EX-220M.step
6.00 x 6.00 x 4.51 mm

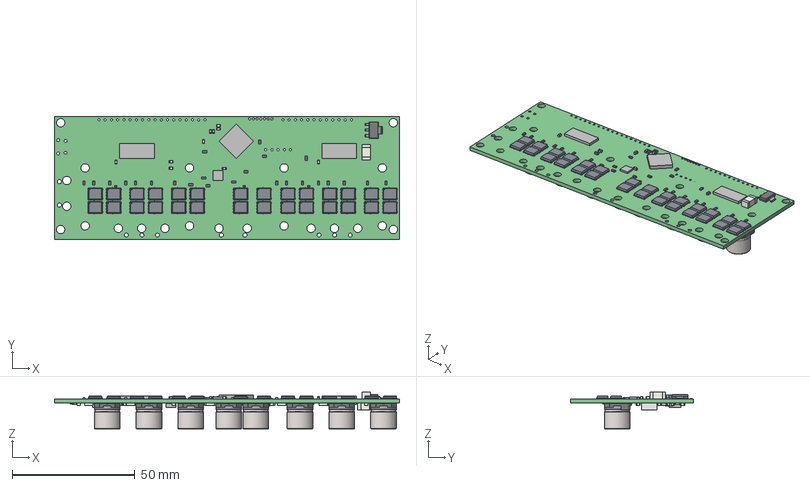
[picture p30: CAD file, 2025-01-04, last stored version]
odriver/ODriveHardware-master/v3/v3.2docs/PCB_v3.2.step
140.5 x 50.0 x 15.0 mm
Board
SOT23-5
Extruded x 201
RES_0402_(1005_metric) x 3
RES_0603_(1608_metric) x 48
SOT223-4
User_Library-DFN5x6_SO8FL_Extruded x 56
User_Library-DFN5x6_SO8FL_Extruded_2 x 56
User_Library-DFN5x6_SO8FL_Cylinder x 28
User_Library-DFN5x6_SO8FL_Extruded_3 x 28
User_Library-DFN5x6_SO8FL_Extruded_4 x 28
User_Library-DFN5x6_SO8FL_Extruded_5 x 112
User_Library-DFN5x6_SO8FL_Extruded_6 x 28
CAP_Alum_Elec_Size_G x 8

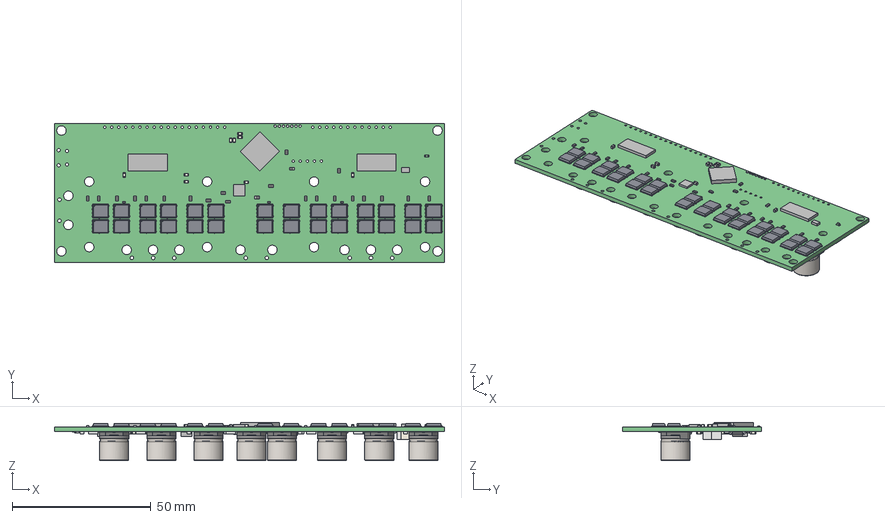
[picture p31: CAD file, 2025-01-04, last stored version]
odriver/ODriveHardware-master/v3/v3.3docs/PCB_v3.3.step
140.5 x 50.0 x 13.8 mm
Board
Extruded x 198
SOT23-5
RES_0402_(1005_metric) x 3
RES_0603_(1608_metric) x 47
SOT223-4
User_Library-DFN5x6_SO8FL_Extruded x 56
User_Library-DFN5x6_SO8FL_Extruded_2 x 56
User_Library-DFN5x6_SO8FL_Cylinder x 28
User_Library-DFN5x6_SO8FL_Extruded_3 x 28
User_Library-DFN5x6_SO8FL_Extruded_4 x 28
User_Library-DFN5x6_SO8FL_Extruded_5 x 112
User_Library-DFN5x6_SO8FL_Extruded_6 x 28
CAP_Alum_Elec_Size_G x 8
LED_0603_APT1608_GREEN

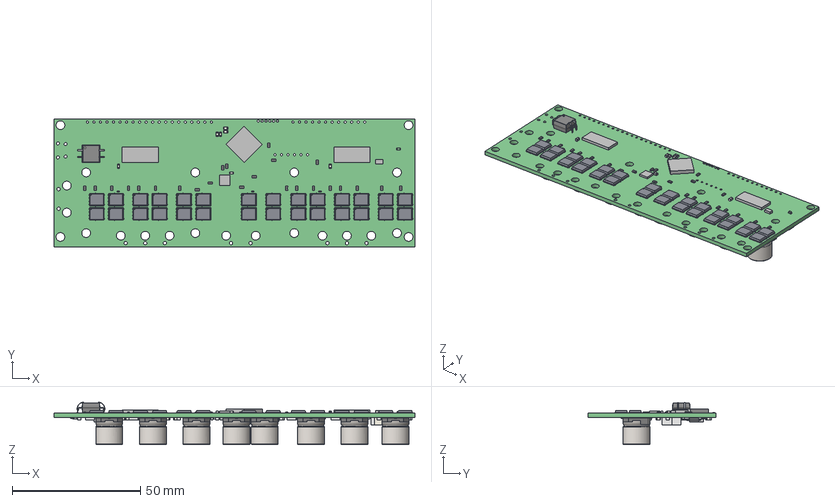
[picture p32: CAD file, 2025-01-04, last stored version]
odriver/ODriveHardware-master/v3/v3.5docs/PCB_v3.5.step
140.5 x 50.0 x 16.4 mm
Board
RES_0603_(1608_metric) x 53
Extruded x 206
Open_CASCADE_STEP_translator_6.8_2.1
Open_CASCADE_STEP_translator_6.8_2.2.1
Leader x 4
SOT23-5
RES_0402_(1005_metric) x 3
SOT223-4
User_Library-DFN5x6_SO8FL_Extruded x 56
User_Library-DFN5x6_SO8FL_Extruded_2 x 56
User_Library-DFN5x6_SO8FL_Cylinder x 28
User_Library-DFN5x6_SO8FL_Extruded_3 x 28
User_Library-DFN5x6_SO8FL_Extruded_4 x 28
User_Library-DFN5x6_SO8FL_Extruded_5 x 112
User_Library-DFN5x6_SO8FL_Extruded_6 x 28
CAP_Alum_Elec_Size_G x 8
LED_0603_APT1608_GREEN

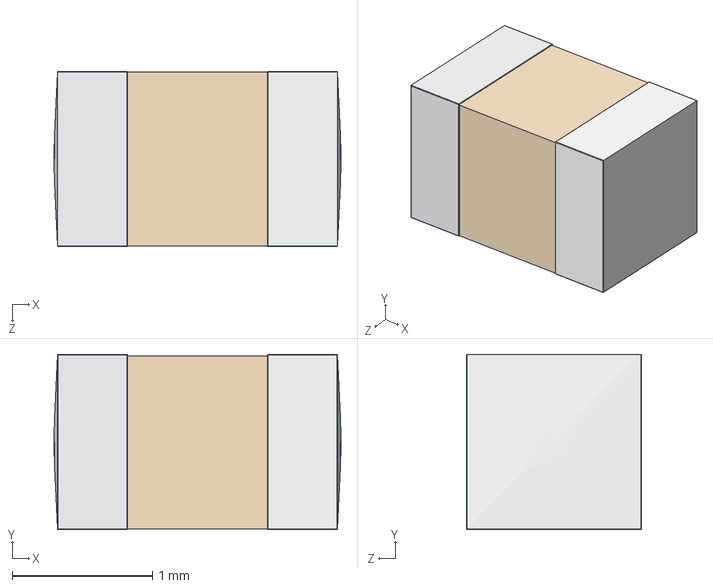
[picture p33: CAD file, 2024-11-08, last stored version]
ts_foc_fw/EG2134_single_motor/BLDC_driver/step_modle/User Library-SMD Ceramic Capacitors_0805 (2012)_DG.step
2.05 x 1.25 x 1.25 mm

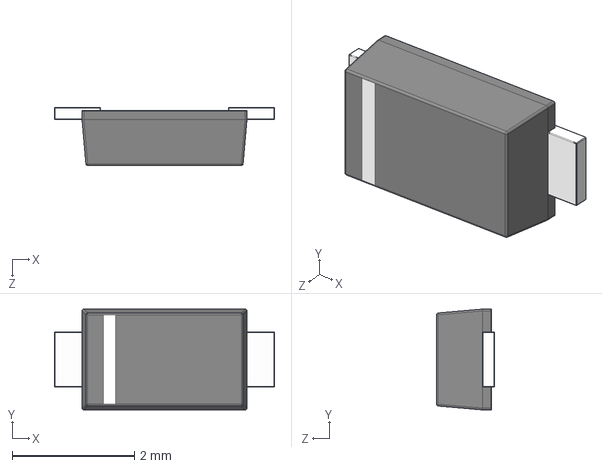
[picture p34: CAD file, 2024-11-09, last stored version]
ts_foc_fw/EG2134_single_motor/EG2134_single_motor_drive/3D_Modle/User Library-SOD-123FL CASE 498.step
3.60 x 1.65 x 0.951 mm

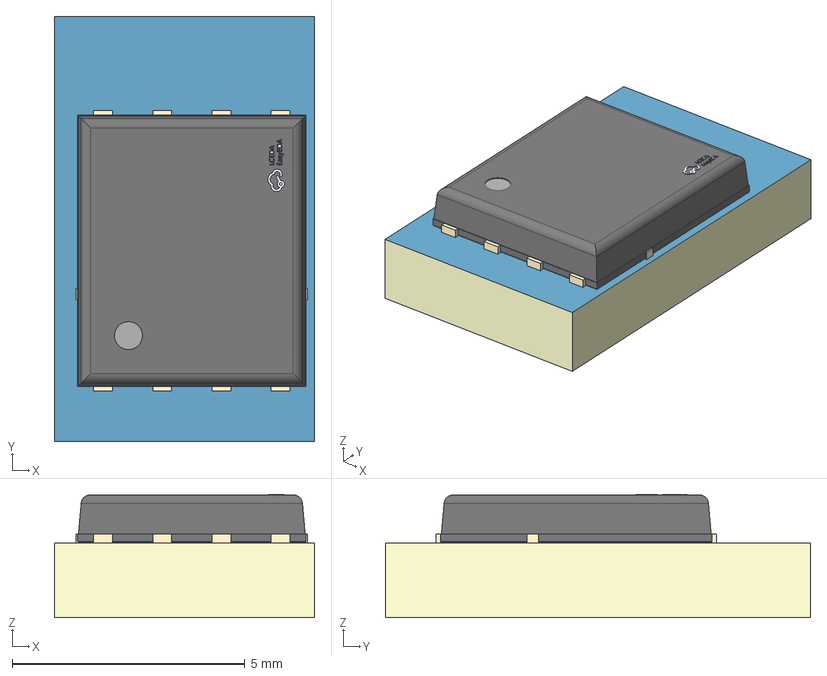
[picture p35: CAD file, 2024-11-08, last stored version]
ts_foc_fw/EG2134_single_motor/BLDC_driver/step_modle/RU3089M-C.step
5.59 x 9.13 x 2.65 mm
TopTrack
BottomTrack
Board

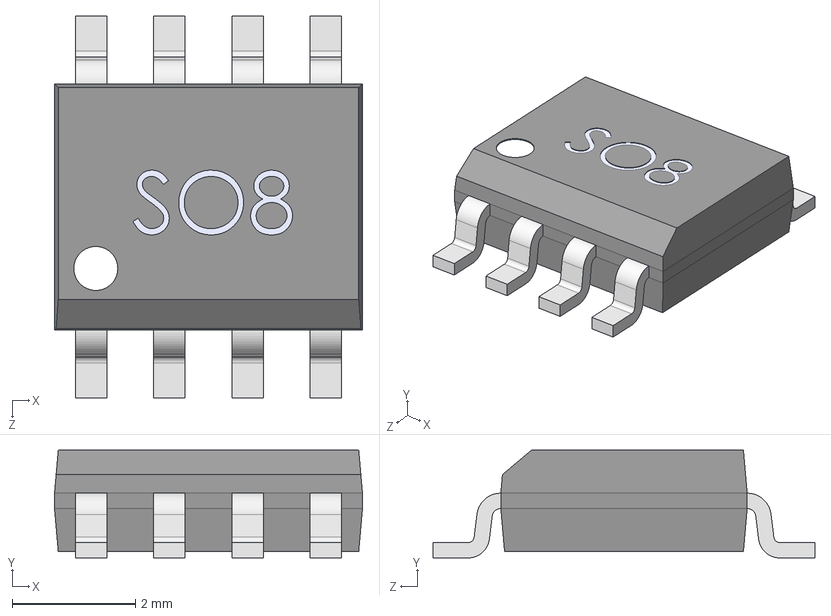
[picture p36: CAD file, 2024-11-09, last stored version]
ts_foc_fw/EG2134_single_motor/EG2134_single_motor_drive/3D_Modle/User Library-SOIC8_JEDEC_MS-012AA.step
5.00 x 1.75 x 6.20 mm

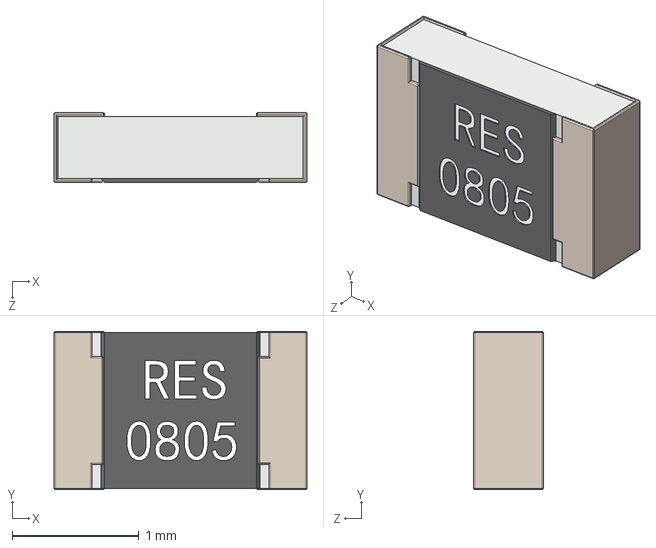
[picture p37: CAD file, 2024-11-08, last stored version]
ts_foc_fw/EG2134_single_motor/BLDC_driver/step_modle/User Library-RES0805-2.STEP
2.00 x 1.25 x 0.55 mm

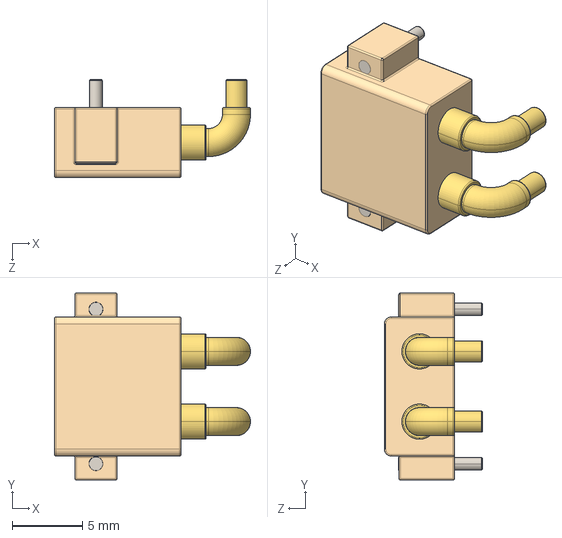
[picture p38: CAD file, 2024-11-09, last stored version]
ts_foc_fw/EG2134_single_motor/EG2134_single_motor_drive/3D_Modle/User Library-XT30PW-M.step
13.9 x 13.3 x 7.00 mm

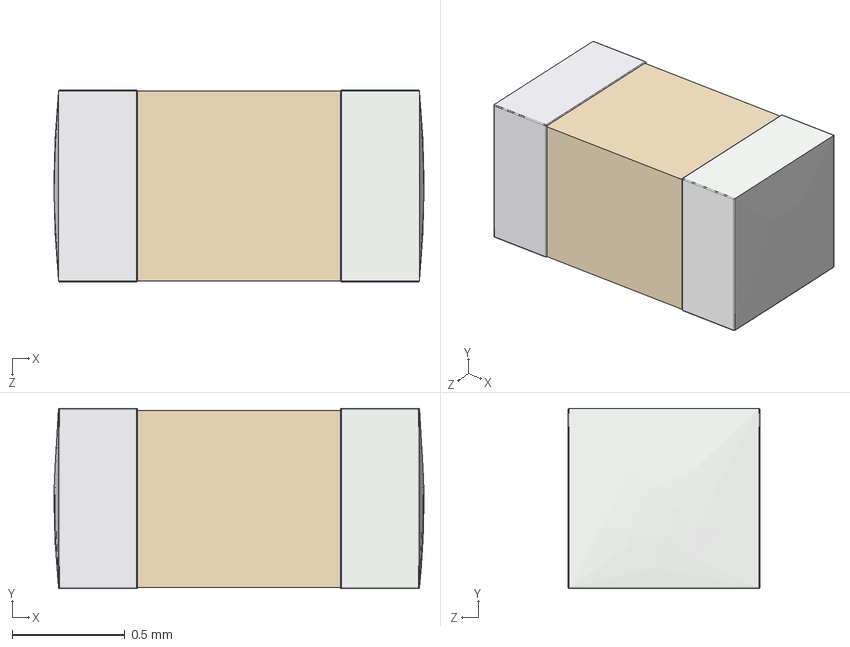
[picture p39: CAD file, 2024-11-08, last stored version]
ts_foc_fw/EG2134_single_motor/BLDC_driver/step_modle/User Library-SMD Ceramic Capacitors_0603 (1608)_CH.step
1.64 x 0.8 x 0.85 mm

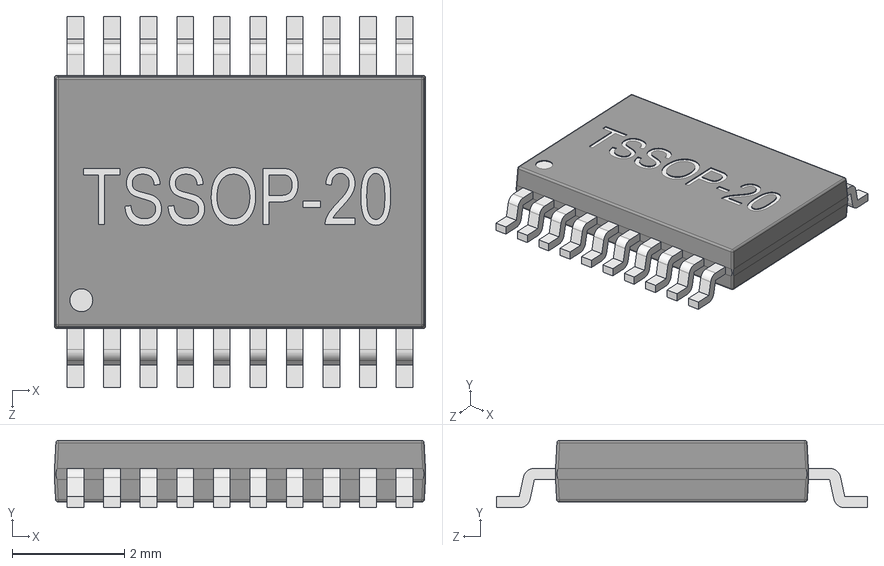
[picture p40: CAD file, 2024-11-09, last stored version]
ts_foc_fw/EG2134_single_motor/EG2134_single_motor_drive/3D_Modle/User Library-tssop-20-1.step
6.60 x 1.20 x 6.60 mm

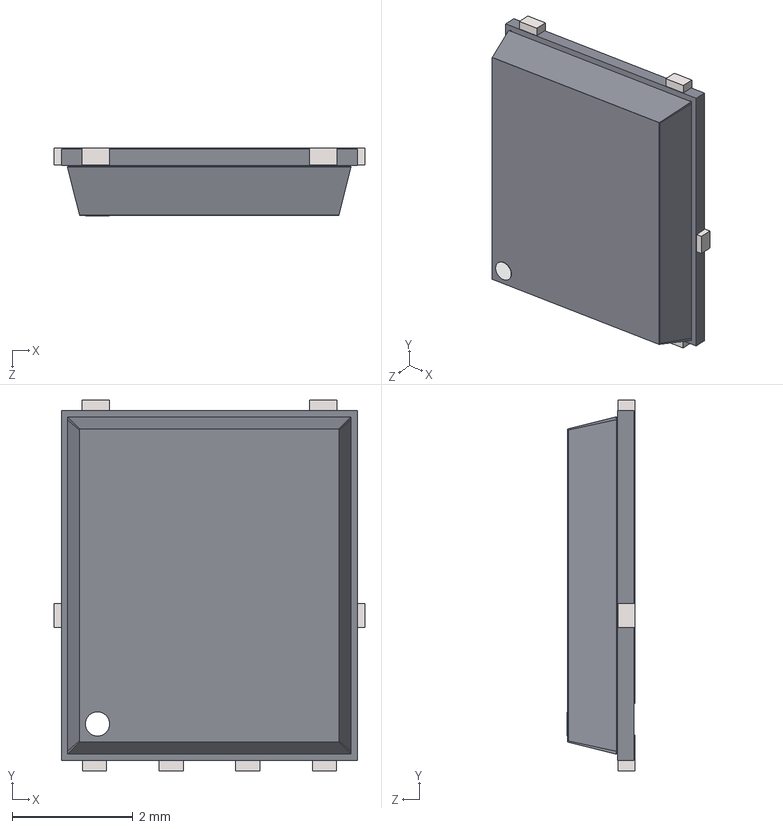
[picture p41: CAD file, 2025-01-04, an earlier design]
odriver/ODriveHardware-master/v2/User Library-DFN5x6_SO8FL.STEP
5.15 x 6.15 x 1.13 mm
User Library-DFN5x6_SO8FL_Extruded x 2
User Library-DFN5x6_SO8FL_Extruded_2 x 2
User Library-DFN5x6_SO8FL_Cylinder
User Library-DFN5x6_SO8FL_Extruded_3
User Library-DFN5x6_SO8FL_Extruded_4
User Library-DFN5x6_SO8FL_Extruded_5 x 4
User Library-DFN5x6_SO8FL_Extruded_6

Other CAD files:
odriver/ODriveHardware-master/v3/v3.4docs/PCB_v3.4.step

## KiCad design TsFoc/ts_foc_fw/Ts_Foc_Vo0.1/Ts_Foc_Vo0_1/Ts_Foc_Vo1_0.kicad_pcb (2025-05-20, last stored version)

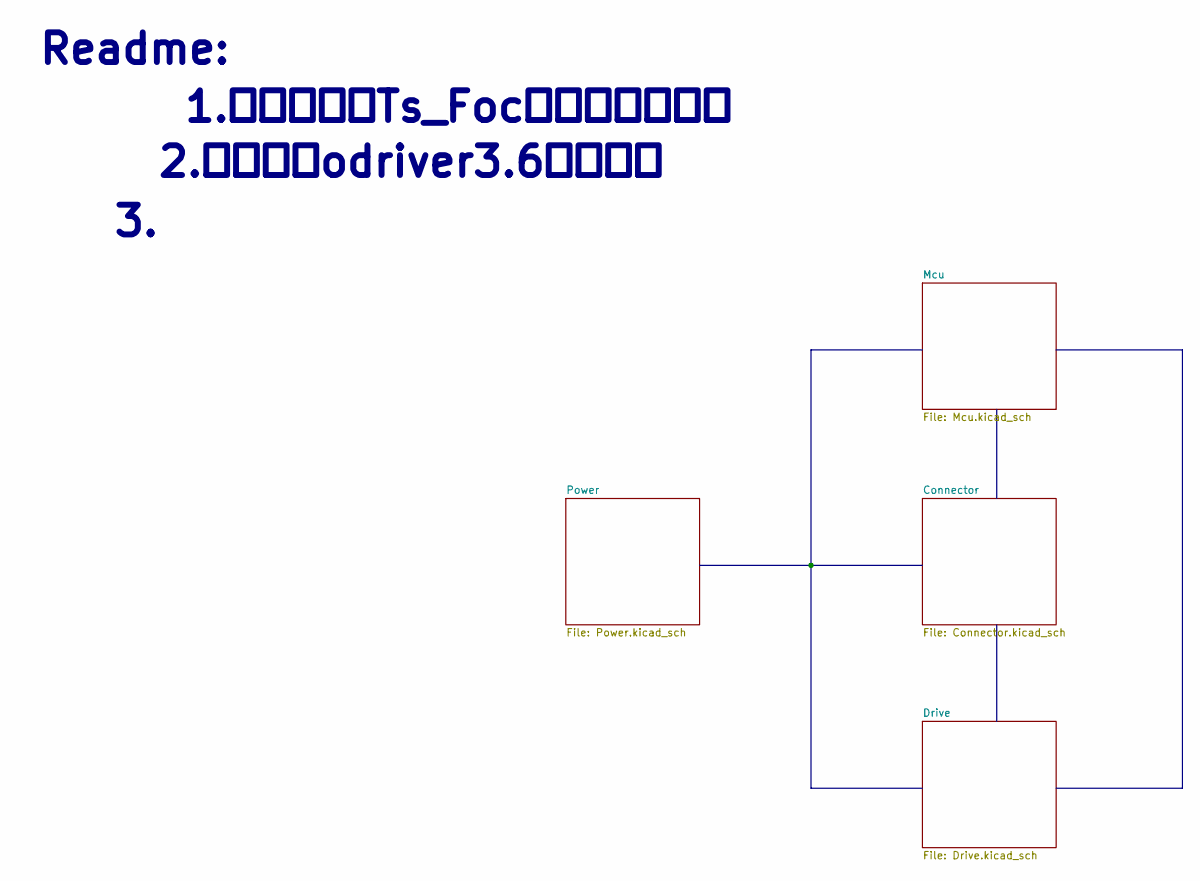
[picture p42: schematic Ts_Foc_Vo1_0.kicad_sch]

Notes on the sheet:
2.布局参考odriver3.6开源版本
1.本项目根据Ts_Foc单电机版本迭代
Readme:

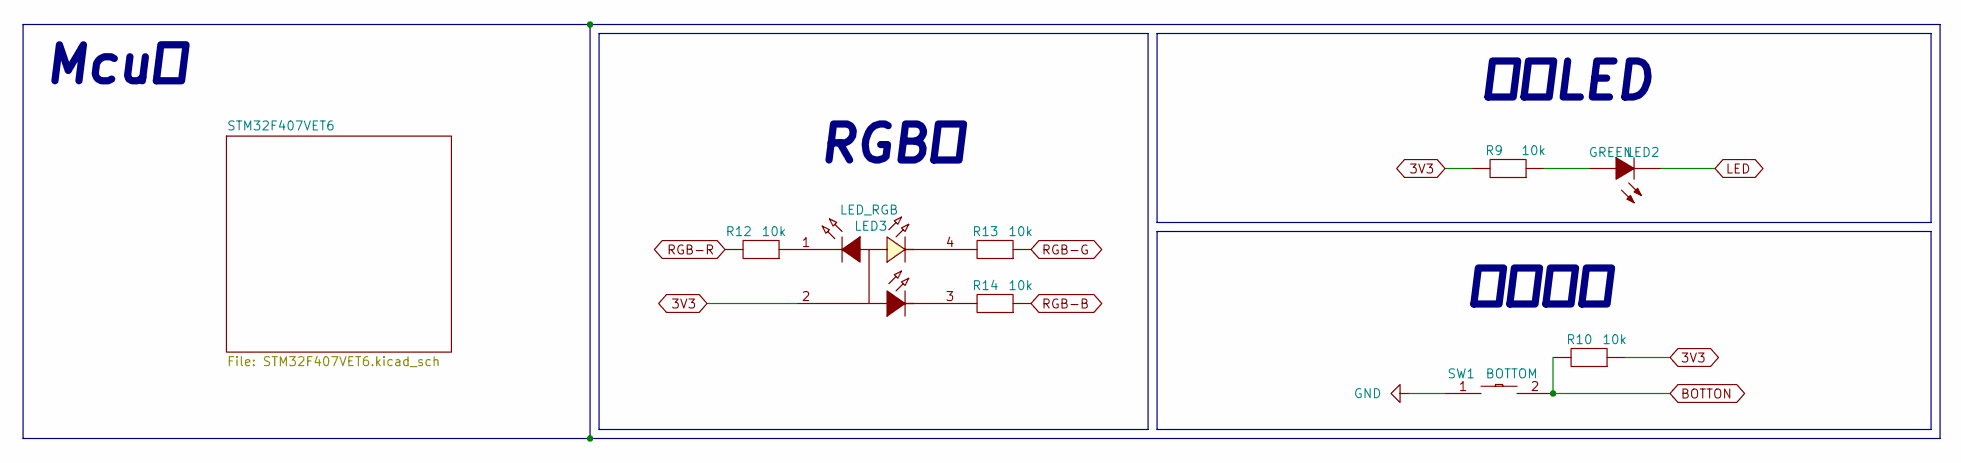
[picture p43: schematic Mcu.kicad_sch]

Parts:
LED2: GREEN; LED_0603
LED3: LED_RGB; LED-RGB-SMD_4P
R9, R10, R12, R13, R14: 10k; Res_0402
SW1: BOTTOM

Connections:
3V3: LED3.2 (COM+), R9.2, R10.1; also elsewhere on the board
BOTTON: R10.2, SW1.2; also elsewhere on the board
GND: SW1.1; also elsewhere on the board
LED: LED2.1 (K); also elsewhere on the board
unnamed: LED2.2 (A), R9.1
unnamed: LED3.3 (B-), R14.2
unnamed: LED3.4 (G-), R13.2
unnamed: LED3.1 (R-), R12.1
RGB-B: R14.1; also elsewhere on the board
RGB-G: R13.1; also elsewhere on the board
RGB-R: R12.2; also elsewhere on the board

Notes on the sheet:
用户按键
用户LED
Mcu：
RGB灯

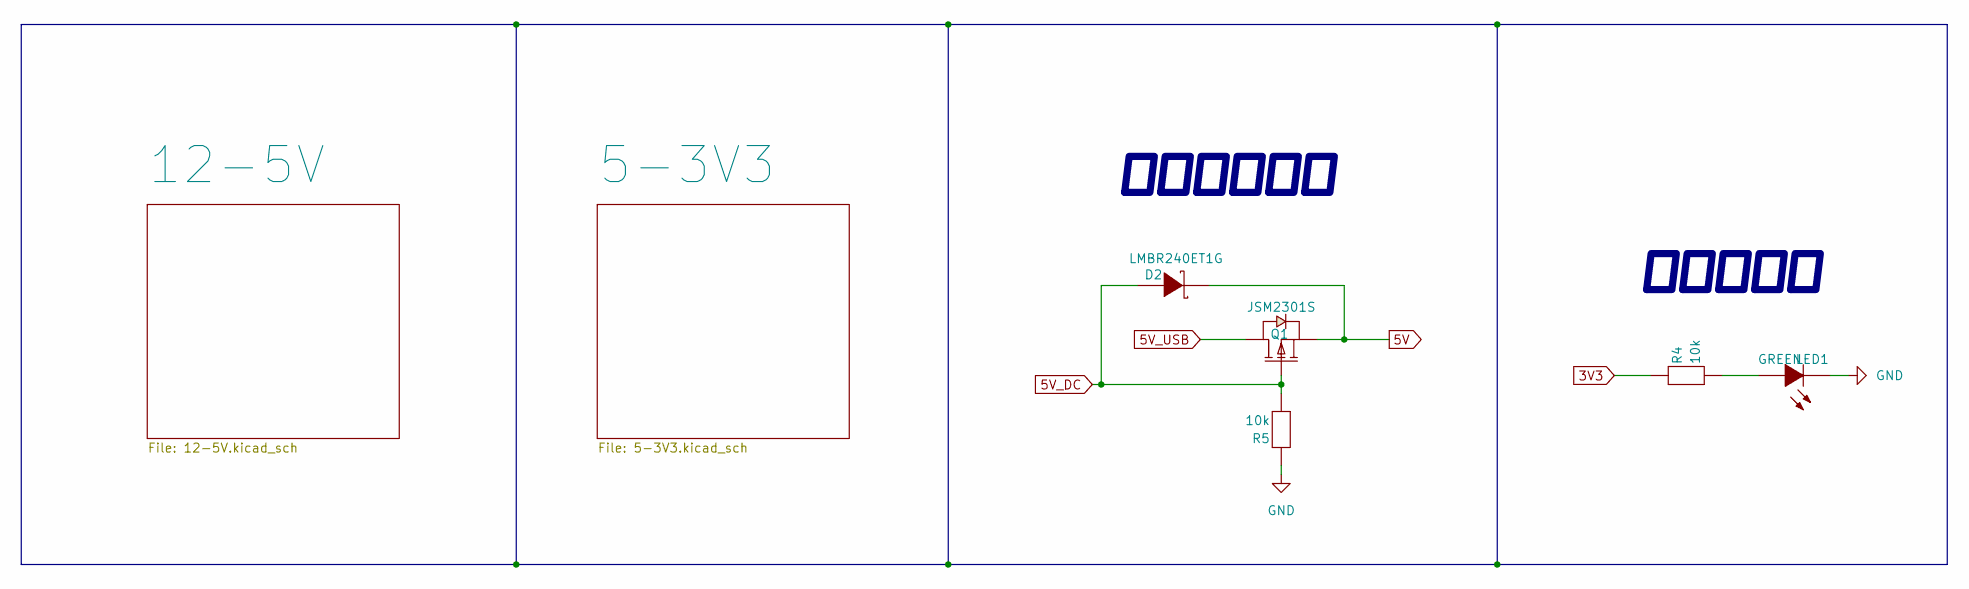
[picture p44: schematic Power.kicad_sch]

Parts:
D2: LMBR240ET1G; LMBR240ET1G_SOD323HE
LED1: GREEN; LED_0603
Q1: JSM2301S; JSM2301S_SOT-23
R4, R5: 10k; Res_0402

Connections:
3V3: R4.2; also elsewhere on the board
5V: D2.1 (C), Q1.2 (S); also elsewhere on the board
5V_DC: D2.2 (A), Q1.1 (G), R5.1; also elsewhere on the board
5V_USB: Q1.3 (D)
GND: LED1.1 (K), R5.2; also elsewhere on the board
unnamed: LED1.2 (A), R4.1

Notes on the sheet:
电源指示灯
强弱电源切换

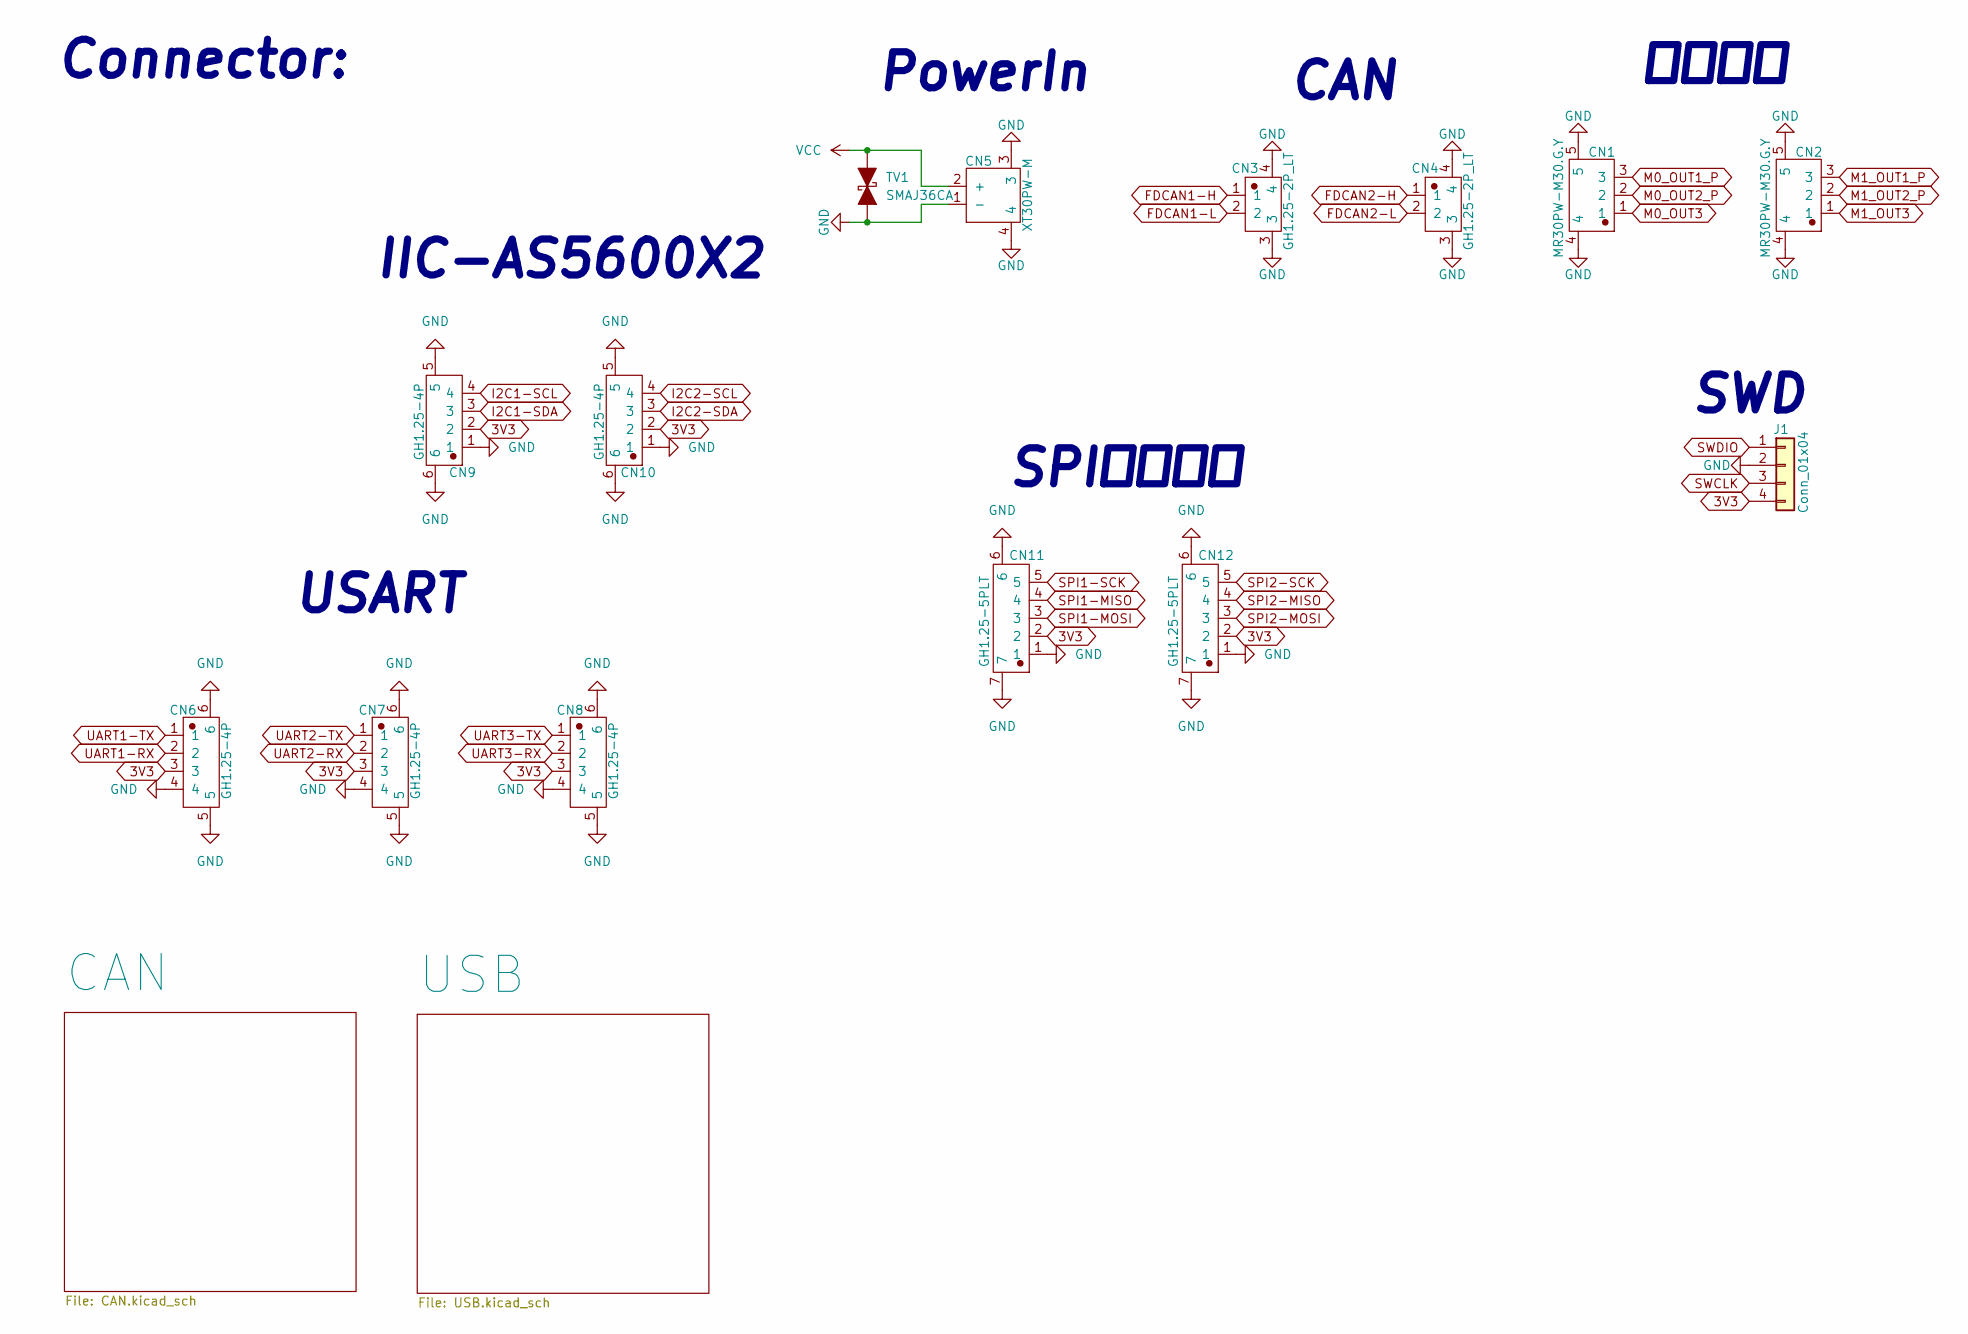
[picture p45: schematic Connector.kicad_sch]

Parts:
CN1, CN2: MR30PW-M30.G.Y; MR30PW-M30-G-Y
CN3, CN4: GH1.25-2P_LT; GH1.25_1X2
CN5: XT30PW-M
CN6, CN7, CN8, CN9, CN10: GH1.25-4P; GH1.25_CONN-SMD_4P-P1.25
CN11, CN12: GH1.25-5PLT; GH1.25_CONN-SMD_5P-P1.25
J1: Conn_01x04; PinHeader_1x04_P2.54mm_Vertical
TV1: SMAJ36CA; SMA_L4.4

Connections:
3V3: CN6.3, CN7.3, CN8.3, CN9.2, CN10.2, CN11.2, CN12.2, J1.4; also elsewhere on the board
FDCAN1-H: CN3.1; also elsewhere on the board
FDCAN1-L: CN3.2; also elsewhere on the board
FDCAN2-H: CN4.1; also elsewhere on the board
FDCAN2-L: CN4.2; also elsewhere on the board
GND: CN1.4, CN1.5, CN2.4, CN2.5, CN3.3, CN3.4, CN4.3, CN4.4, CN5.1 (-), CN5.3, CN5.4, CN6.4, CN6.5, CN6.6, CN7.4, CN7.5, CN7.6, CN8.4, CN8.5, CN8.6, CN9.1, CN9.5, CN9.6, CN10.1, CN10.5, CN10.6, CN11.1, CN11.6, CN11.7, CN12.1, CN12.6, CN12.7, J1.2, TV1.1 (K); also elsewhere on the board
I2C1-SCL: CN9.4; also elsewhere on the board
I2C1-SDA: CN9.3; also elsewhere on the board
I2C2-SCL: CN10.4; also elsewhere on the board
I2C2-SDA: CN10.3; also elsewhere on the board
M0_OUT1_P: CN1.3; also elsewhere on the board
M0_OUT2_P: CN1.2; also elsewhere on the board
M0_OUT3: CN1.1; also elsewhere on the board
M1_OUT1_P: CN2.3; also elsewhere on the board
M1_OUT2_P: CN2.2; also elsewhere on the board
M1_OUT3: CN2.1; also elsewhere on the board
SPI1-MISO: CN11.4; also elsewhere on the board
SPI1-MOSI: CN11.3; also elsewhere on the board
SPI1-SCK: CN11.5; also elsewhere on the board
SPI2-MISO: CN12.4; also elsewhere on the board
SPI2-MOSI: CN12.3; also elsewhere on the board
SPI2-SCK: CN12.5; also elsewhere on the board
SWCLK: J1.3; also elsewhere on the board
SWDIO: J1.1; also elsewhere on the board
UART1-RX: CN6.2; also elsewhere on the board
UART1-TX: CN6.1; also elsewhere on the board
UART2-RX: CN7.2; also elsewhere on the board
UART2-TX: CN7.1; also elsewhere on the board
UART3-RX: CN8.2; also elsewhere on the board
UART3-TX: CN8.1; also elsewhere on the board
VCC: CN5.2 (+), TV1.2 (A); also elsewhere on the board

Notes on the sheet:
CAN
PowerIn
电机接口
IIC-AS5600X2
Connector:
SPI预留接口
USART
SWD

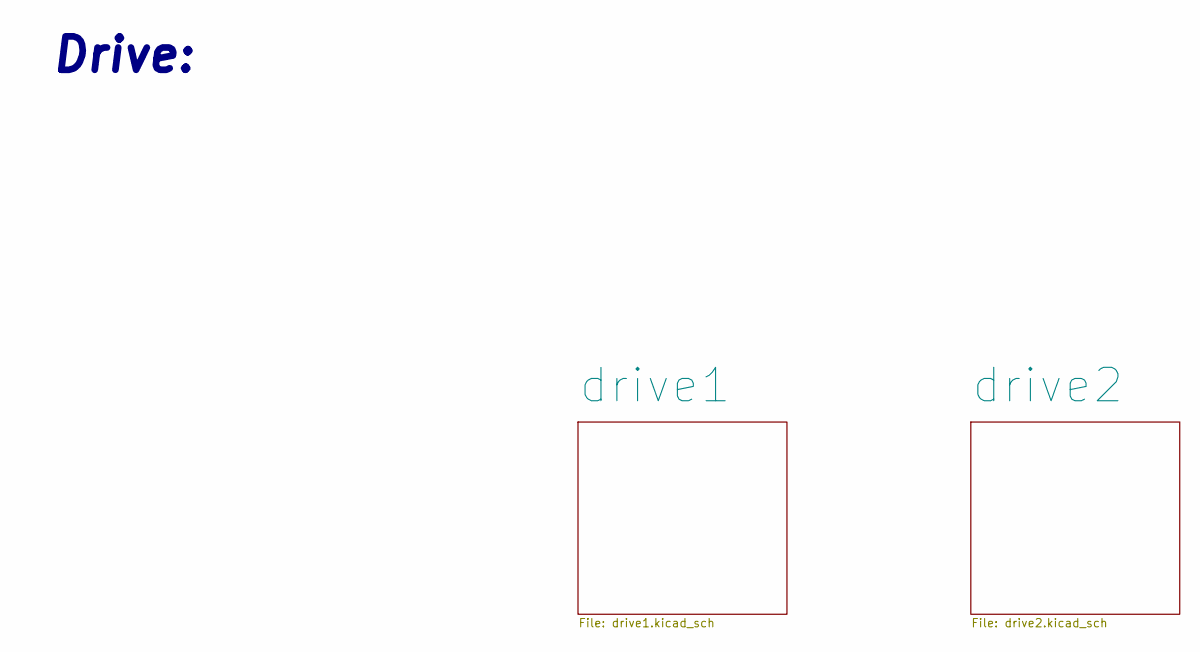
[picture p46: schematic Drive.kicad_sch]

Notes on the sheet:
Drive:

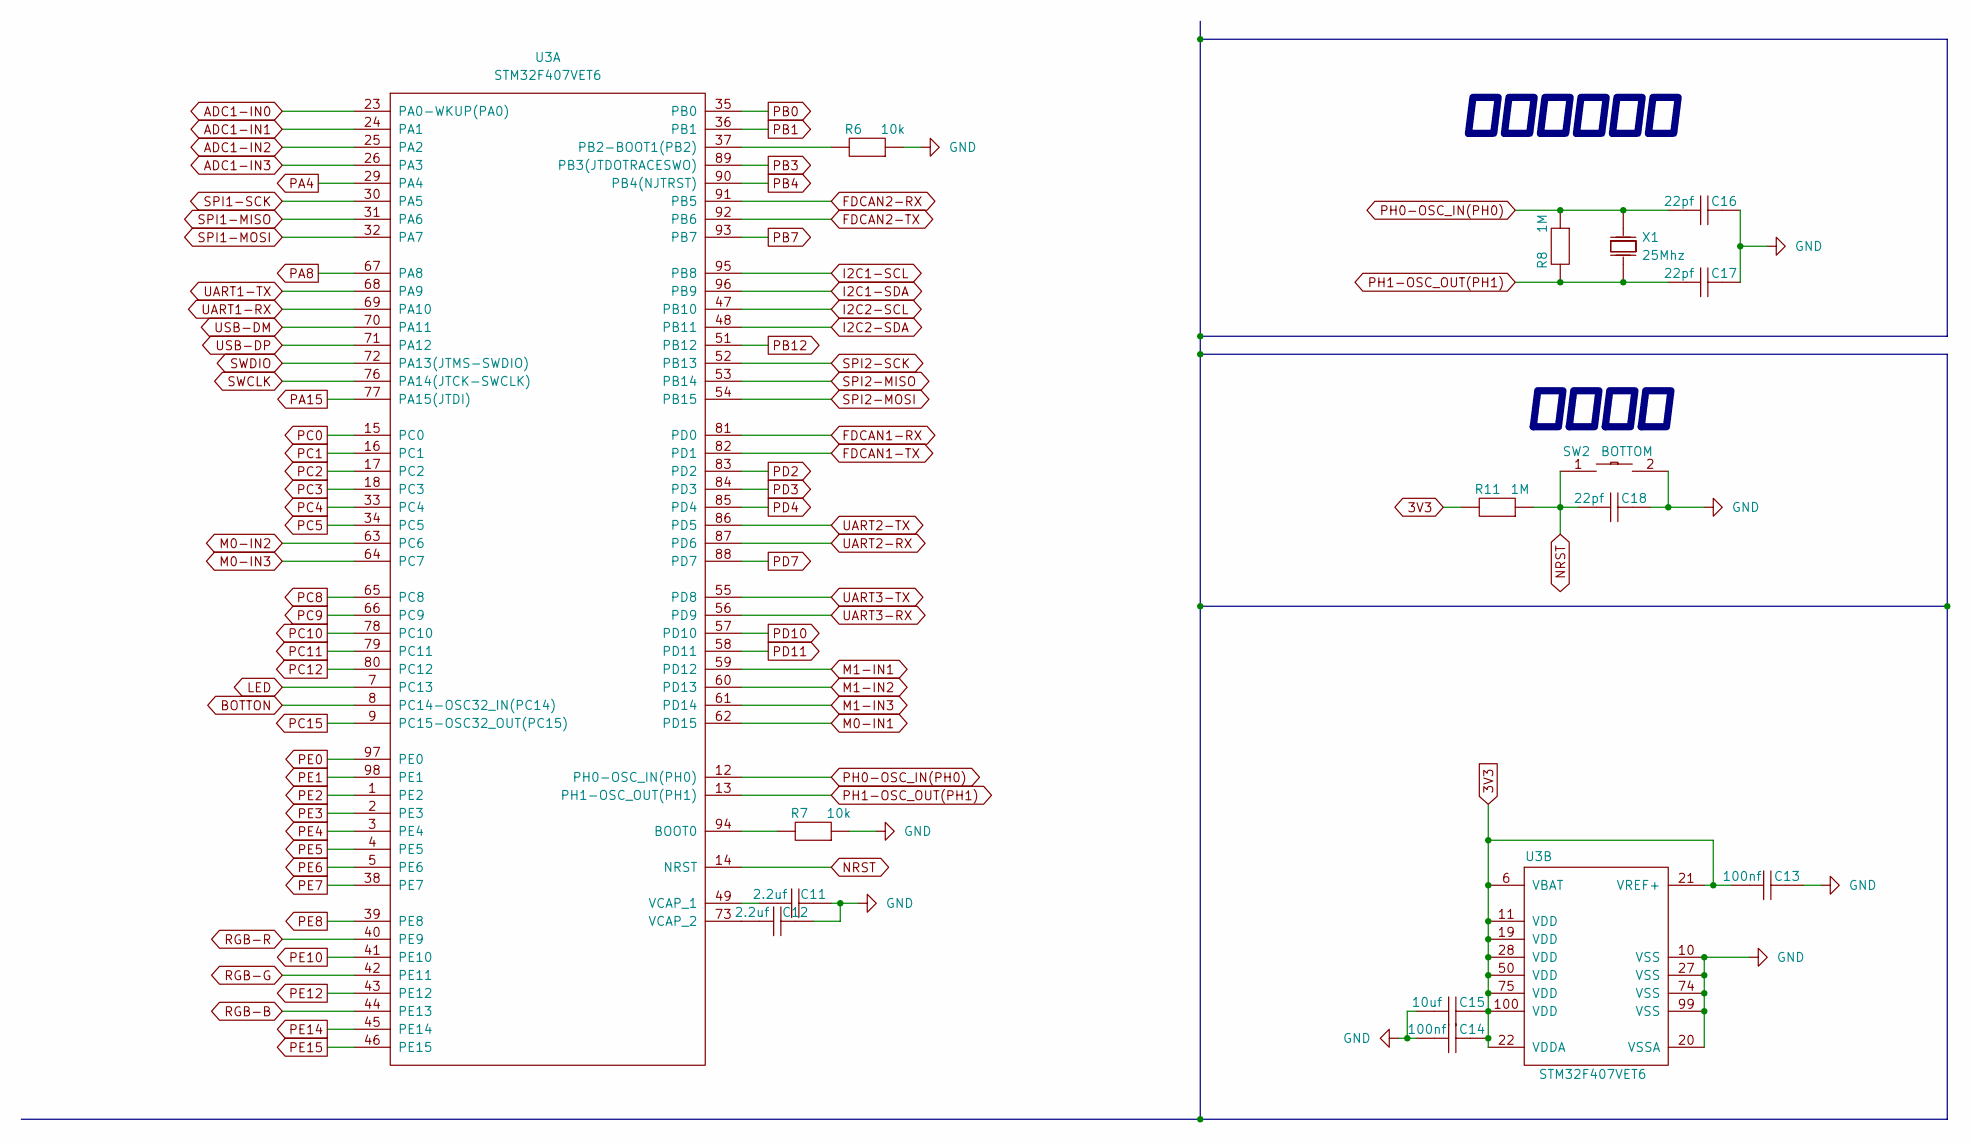
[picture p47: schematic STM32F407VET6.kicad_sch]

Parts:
C11, C12: 2.2uf; CAP_0402
C13, C14: 100nf; CAP_0402
C15: 10uf; CAP_0402
C16, C17, C18: 22pf; CAP_0402
R6, R7: 10k; Res_0402
R8, R11: 1M; Res_0402
SW2: BOTTOM
U3: STM32F407VET6; STM32_F407_VET6_LQFP-100
X1: 25Mhz; XTAL-SMD

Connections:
3V3: C13.2, C14.1, C15.1, R11.2, U3.6 (VBAT), U3.11 (VDD), U3.19 (VDD), U3.21 (VREF+), U3.22 (VDDA), U3.28 (VDD), U3.50 (VDD), U3.75 (VDD), U3.100 (VDD); also elsewhere on the board
ADC1-IN0: U3.23 (PA0-WKUP(PA0)); also elsewhere on the board
ADC1-IN1: U3.24 (PA1); also elsewhere on the board
ADC1-IN2: U3.25 (PA2); also elsewhere on the board
ADC1-IN3: U3.26 (PA3); also elsewhere on the board
BOTTON: U3.8 (PC14-OSC32_IN(PC14)); also elsewhere on the board
FDCAN1-RX: U3.81 (PD0); also elsewhere on the board
FDCAN1-TX: U3.82 (PD1); also elsewhere on the board
FDCAN2-RX: U3.91 (PB5); also elsewhere on the board
FDCAN2-TX: U3.92 (PB6); also elsewhere on the board
GND: C11.1, C12.1, C13.1, C14.2, C15.2, C16.1, C17.1, C18.1, R6.1, R7.1, SW2.2, U3.10 (VSS), U3.20 (VSSA), U3.27 (VSS), U3.74 (VSS), U3.99 (VSS); also elsewhere on the board
I2C1-SCL: U3.95 (PB8); also elsewhere on the board
I2C1-SDA: U3.96 (PB9); also elsewhere on the board
I2C2-SCL: U3.47 (PB10); also elsewhere on the board
I2C2-SDA: U3.48 (PB11); also elsewhere on the board
LED: U3.7 (PC13); also elsewhere on the board
M0-IN1: U3.62 (PD15); also elsewhere on the board
M0-IN2: U3.63 (PC6); also elsewhere on the board
M0-IN3: U3.64 (PC7); also elsewhere on the board
M1-IN1: U3.59 (PD12); also elsewhere on the board
M1-IN2: U3.60 (PD13); also elsewhere on the board
M1-IN3: U3.61 (PD14); also elsewhere on the board
NRST: C18.2, R11.1, SW2.1, U3.14 (NRST)
unnamed: R7.2, U3.94 (BOOT0)
unnamed: R6.2, U3.37 (PB2-BOOT1(PB2))
unnamed: C11.2, U3.49 (VCAP_1)
unnamed: C12.2, U3.73 (VCAP_2)
PA4: U3.29 (PA4)
PA8: U3.67 (PA8)
PA15: U3.77 (PA15(JTDI))
PB0: U3.35 (PB0)
PB1: U3.36 (PB1)
PB3: U3.89 (PB3(JTDOTRACESWO))
PB4: U3.90 (PB4(NJTRST))
PB7: U3.93 (PB7)
PB12: U3.51 (PB12)
PC0: U3.15 (PC0)
PC1: U3.16 (PC1)
PC2: U3.17 (PC2)
PC3: U3.18 (PC3)
PC4: U3.33 (PC4)
PC5: U3.34 (PC5)
PC8: U3.65 (PC8)
PC9: U3.66 (PC9)
PC10: U3.78 (PC10)
PC11: U3.79 (PC11)
PC12: U3.80 (PC12)
PC15: U3.9 (PC15-OSC32_OUT(PC15))
PD2: U3.83 (PD2)
PD3: U3.84 (PD3)
PD4: U3.85 (PD4)
PD7: U3.88 (PD7)
PD10: U3.57 (PD10)
PD11: U3.58 (PD11)
PE0: U3.97 (PE0)
PE1: U3.98 (PE1)
PE2: U3.1 (PE2)
PE3: U3.2 (PE3)
PE4: U3.3 (PE4)
PE5: U3.4 (PE5)
PE6: U3.5 (PE6)
PE7: U3.38 (PE7)
PE8: U3.39 (PE8)
PE10: U3.41 (PE10)
PE12: U3.43 (PE12)
PE14: U3.45 (PE14)
PE15: U3.46 (PE15)
PH0-OSC_IN(PH0): C16.2, R8.1, U3.12 (PH0-OSC_IN(PH0)), X1.2 (OSC2)
PH1-OSC_OUT(PH1): C17.2, R8.2, U3.13 (PH1-OSC_OUT(PH1)), X1.1 (OSC1)
RGB-B: U3.44 (PE13); also elsewhere on the board
RGB-G: U3.42 (PE11); also elsewhere on the board
RGB-R: U3.40 (PE9); also elsewhere on the board
SPI1-MISO: U3.31 (PA6); also elsewhere on the board
SPI1-MOSI: U3.32 (PA7); also elsewhere on the board
SPI1-SCK: U3.30 (PA5); also elsewhere on the board
SPI2-MISO: U3.53 (PB14); also elsewhere on the board
SPI2-MOSI: U3.54 (PB15); also elsewhere on the board
SPI2-SCK: U3.52 (PB13); also elsewhere on the board
SWCLK: U3.76 (PA14(JTCK-SWCLK)); also elsewhere on the board
SWDIO: U3.72 (PA13(JTMS-SWDIO)); also elsewhere on the board
UART1-RX: U3.69 (PA10); also elsewhere on the board
UART1-TX: U3.68 (PA9); also elsewhere on the board
UART2-RX: U3.87 (PD6); also elsewhere on the board
UART2-TX: U3.86 (PD5); also elsewhere on the board
UART3-RX: U3.56 (PD9); also elsewhere on the board
UART3-TX: U3.55 (PD8); also elsewhere on the board
USB-DM: U3.70 (PA11); also elsewhere on the board
USB-DP: U3.71 (PA12); also elsewhere on the board

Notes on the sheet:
外部高速晶振
复位电路

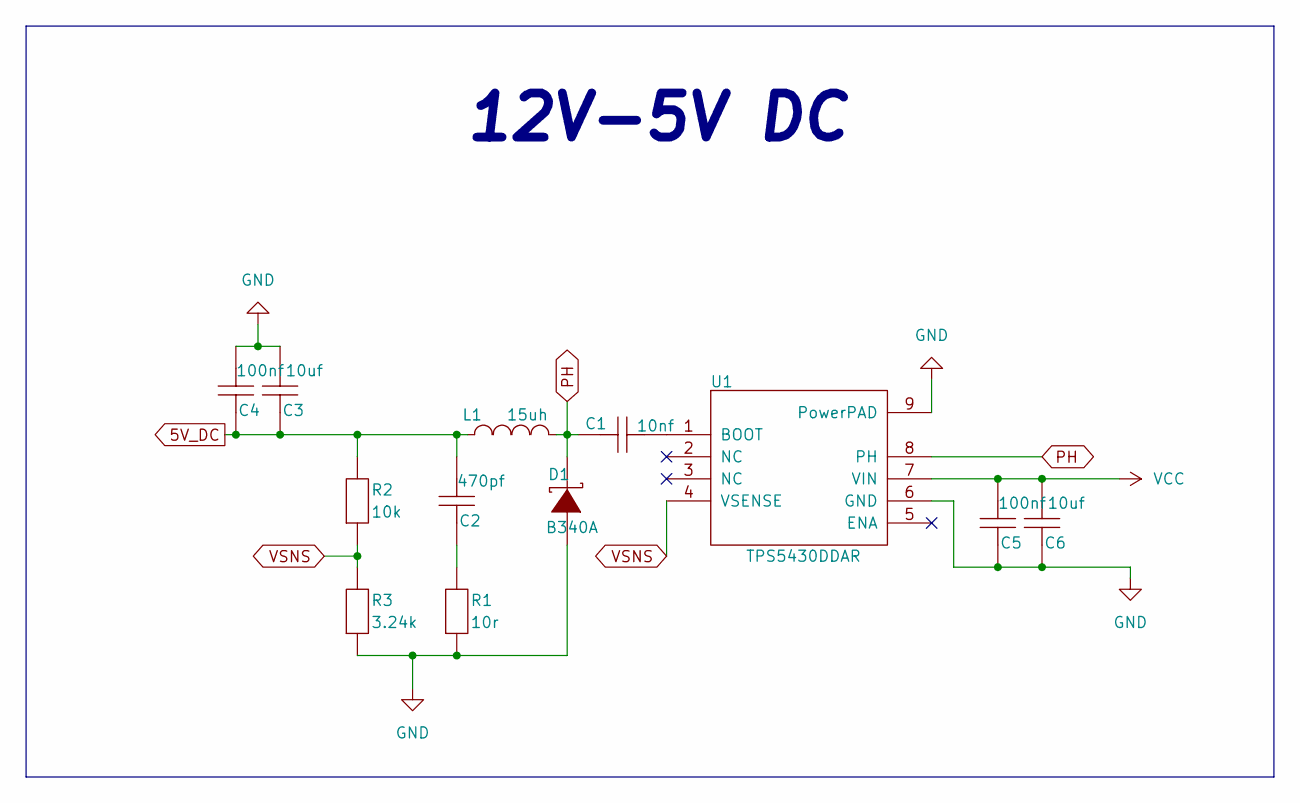
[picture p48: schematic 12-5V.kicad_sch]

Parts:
C1: 10nf; CAP_0402
C2: 470pf; CAP_0402
C3, C6: 10uf; CAP_0402
C4, C5: 100nf; CAP_0402
D1: B340A; B340A_SMA
L1: 15uh; IND-SMD
R1: 10r; Res_0402
R2: 10k; Res_0402
R3: 3.24k; Res_0402
U1: TPS5430DDAR; TPS5430DDAR_ESOP-8

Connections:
5V_DC: C2.2, C3.1, C4.1, L1.1, R2.2; also elsewhere on the board
GND: C3.2, C4.2, C5.1, C6.1, D1.2 (A), R1.1, R3.1, U1.6 (GND), U1.9 (PowerPAD); also elsewhere on the board
unnamed: C2.1, R1.2
unnamed: C1.2, U1.1 (BOOT)
PH: C1.1, D1.1 (K), L1.2, U1.8 (PH)
VCC: C5.2, C6.2, U1.7 (VIN); also elsewhere on the board
VSNS: R2.1, R3.2, U1.4 (VSENSE)

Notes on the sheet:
12V-5V DC

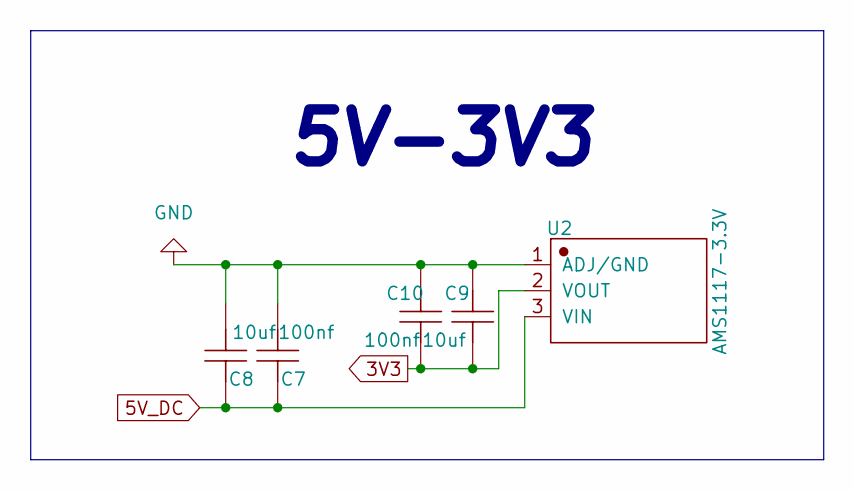
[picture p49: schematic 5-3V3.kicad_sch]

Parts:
C7, C10: 100nf; CAP_0402
C8, C9: 10uf; CAP_0402
U2: AMS1117-3.3V; AMS1117_SOT-89

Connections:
3V3: C9.2, C10.2, U2.2 (VOUT); also elsewhere on the board
5V_DC: C7.1, C8.1, U2.3 (VIN); also elsewhere on the board
GND: C7.2, C8.2, C9.1, C10.1, U2.1 (ADJ/GND); also elsewhere on the board

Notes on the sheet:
5V-3V3

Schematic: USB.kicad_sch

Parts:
R33, R34: 5.1K; Res_0402
R35, R36: 22r; Res_0402
USB1: TYPE-C-16P; USB-C-16P-SMD

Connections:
5V-USB: USB1.A4B9 (VBUS), USB1.B4A9 (VBUS)
DM: R35.2, USB1.A7 (D-), USB1.B7 (D-)
DP: R36.2, USB1.A6 (D+), USB1.B6 (D+)
GND: R33.1, R34.1, USB1.1 (SHELL), USB1.2 (SHELL), USB1.3 (SHELL), USB1.4 (SHELL), USB1.A1B12 (GND), USB1.B1A12 (GND); also elsewhere on the board
unnamed: R34.2, USB1.A8 (SBU1)
unnamed: R33.2, USB1.B8 (SBU2)
USB-DM: R35.1; also elsewhere on the board
USB-DP: R36.1; also elsewhere on the board

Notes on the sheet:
USB_TYPE-C

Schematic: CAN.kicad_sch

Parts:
R31, R32: 120r; Res_0402
U10, U11: SIT1050TK; SIT1050TK_TDFN-8

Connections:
5V: U10.3 (VCC), U11.3 (VCC); also elsewhere on the board
FDCAN1-H: R31.2, U10.7 (CANH); also elsewhere on the board
FDCAN1-L: R31.1, U10.6 (CANL); also elsewhere on the board
FDCAN1-RX: U10.4 (RXD); also elsewhere on the board
FDCAN1-TX: U10.1 (TXD); also elsewhere on the board
FDCAN2-H: R32.2, U11.7 (CANH); also elsewhere on the board
FDCAN2-L: R32.1, U11.6 (CANL); also elsewhere on the board
FDCAN2-RX: U11.4 (RXD); also elsewhere on the board
FDCAN2-TX: U11.1 (TXD); also elsewhere on the board
GND: U10.2 (GND), U10.8 (S), U10.9 (EP), U11.2 (GND), U11.8 (S), U11.9 (EP); also elsewhere on the board
VCC: U10.5 (Vref), U11.5 (Vref); also elsewhere on the board

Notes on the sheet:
CAN收发器

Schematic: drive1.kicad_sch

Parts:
C19: 1uf; CAP_0402
C20, C21, C22, C23: 100nf; CAP_0402
D3, D4, D5: DSK34; DSK_34_SOD-123
D6, D7, D8, D9, D10, D11: 1N4148W; 1N4148W_SOD-123
Q2, Q3, Q4, Q5, Q6, Q7: RU3089M-C; RU3089M-C_PQFN-8
R15, R16: 10mr; Res_1206
R17, R18, R19, R20, R21, R22: 2.2r; Res_0402
U4: EG2133; EG2133_TSSOP
U5, U6: INA240A2PWR; INA240A2PWR_TSSOP-8

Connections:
3V3: U5.5 (VS), U5.6 (REF2), U6.5 (VS), U6.6 (REF2); also elsewhere on the board
5V: D3.2 (A), D4.2 (A), D5.2 (A); also elsewhere on the board
ADC1-IN0: U5.8 (OUT); also elsewhere on the board
ADC1-IN1: U6.8 (OUT); also elsewhere on the board
GND: C19.1, C20.1, U4.8 (GND), U5.4 (GND), U5.7 (REF1), U6.4 (GND), U6.7 (REF1); also elsewhere on the board
M0-IN1: U4.1 (HIN1), U4.4 (LIN1#); also elsewhere on the board
M0-IN2: U4.2 (HIN2), U4.5 (LIN2#); also elsewhere on the board
M0-IN3: U4.3 (HIN3), U4.6 (LIN3#); also elsewhere on the board
M0_GH1: D6.2 (K), R17.2, U4.19 (HO1)
M0_GH2: D8.2 (K), R19.2, U4.16 (HO2)
M0_GH3: D10.2 (K), R21.2, U4.13 (HO3)
M0_GL1: D7.2 (K), R18.2, U4.11 (LO1)
M0_GL2: D9.2 (K), R20.2, U4.10 (LO2)
M0_GL3: D11.2 (K), R22.2, U4.9 (LO3)
M0_OUT1: C21.1, U4.18 (VS1)
M0_OUT1_P: Q2.1 (S), Q2.2 (S), Q2.3 (S), Q3.5 (D), Q3.6 (D), Q3.7 (D), Q3.8 (D), Q3.9 (D), R15.1, U5.3 (IN-); also elsewhere on the board
M0_OUT2: C22.1, U4.15 (VS2)
M0_OUT2_P: Q4.1 (S), Q4.2 (S), Q4.3 (S), Q5.5 (D), Q5.6 (D), Q5.7 (D), Q5.8 (D), Q5.9 (D), R16.1, U6.3 (IN-); also elsewhere on the board
M0_OUT3: C23.1, Q6.1 (S), Q6.2 (S), Q6.3 (S), Q7.5 (D), Q7.6 (D), Q7.7 (D), Q7.8 (D), Q7.9 (D), U4.12 (VS3); also elsewhere on the board
unnamed: C21.2, D3.1 (K), U4.20 (VB1)
unnamed: C22.2, D4.1 (K), U4.17 (VB2)
unnamed: C23.2, D5.1 (K), U4.14 (VB3)
unnamed: D6.1 (A), Q2.4 (G), R17.1
unnamed: D7.1 (A), Q3.4 (G), R18.1
unnamed: D8.1 (A), Q4.4 (G), R19.1
unnamed: D9.1 (A), Q5.4 (G), R20.1
unnamed: D10.1 (A), Q6.4 (G), R21.1
unnamed: D11.1 (A), Q7.4 (G), R22.1
unnamed: C19.2, C20.2, U4.7 (VCC)
unnamed: R15.2, U5.2 (IN+)
unnamed: R16.2, U6.2 (IN+)
PGND: Q3.1 (S), Q3.2 (S), Q3.3 (S), Q5.1 (S), Q5.2 (S), Q5.3 (S), Q7.1 (S), Q7.2 (S), Q7.3 (S); also elsewhere on the board
VCC: Q2.5 (D), Q2.6 (D), Q2.7 (D), Q2.8 (D), Q2.9 (D), Q4.5 (D), Q4.6 (D), Q4.7 (D), Q4.8 (D), Q4.9 (D), Q6.5 (D), Q6.6 (D), Q6.7 (D), Q6.8 (D), Q6.9 (D); also elsewhere on the board

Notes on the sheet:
电流采样
Motor1
三项全桥逆变
EG2133+自举

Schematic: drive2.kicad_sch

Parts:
C24: 1uf; CAP_0402
C25, C26, C27, C28: 100nf; CAP_0402
D12, D13, D14: DSK34; DSK_34_SOD-123
D15, D16, D17, D18, D19, D20: 1N4148W; 1N4148W_SOD-123
Q8, Q9, Q10, Q11, Q12, Q13: RU3089M-C; RU3089M-C_PQFN-8
R23, R24: 10mr; Res_1206
R25, R26, R27, R28, R29, R30: 2.2r; Res_0402
U7: EG2133; EG2133_TSSOP
U8, U9: INA240A2PWR; INA240A2PWR_TSSOP-8

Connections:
3V3: U8.5 (VS), U8.6 (REF2), U9.5 (VS), U9.6 (REF2); also elsewhere on the board
5V: D12.2 (A), D13.2 (A), D14.2 (A); also elsewhere on the board
ADC1-IN2: U8.8 (OUT); also elsewhere on the board
ADC1-IN3: U9.8 (OUT); also elsewhere on the board
GND: C24.1, C25.1, U7.8 (GND), U8.4 (GND), U8.7 (REF1), U9.4 (GND), U9.7 (REF1); also elsewhere on the board
M1-IN1: U7.1 (HIN1), U7.4 (LIN1#); also elsewhere on the board
M1-IN2: U7.2 (HIN2), U7.5 (LIN2#); also elsewhere on the board
M1-IN3: U7.3 (HIN3), U7.6 (LIN3#); also elsewhere on the board
M1_GH1: D15.2 (K), R25.2, U7.19 (HO1)
M1_GH2: D17.2 (K), R27.2, U7.16 (HO2)
M1_GH3: D19.2 (K), R29.2, U7.13 (HO3)
M1_GL1: D16.2 (K), R26.2, U7.11 (LO1)
M1_GL2: D18.2 (K), R28.2, U7.10 (LO2)
M1_GL3: D20.2 (K), R30.2, U7.9 (LO3)
M1_OUT1: C26.1, U7.18 (VS1)
M1_OUT1_P: Q8.1 (S), Q8.2 (S), Q8.3 (S), Q9.5 (D), Q9.6 (D), Q9.7 (D), Q9.8 (D), Q9.9 (D), R23.1, U8.3 (IN-); also elsewhere on the board
M1_OUT2: C27.1, U7.15 (VS2)
M1_OUT2_P: Q10.1 (S), Q10.2 (S), Q10.3 (S), Q11.5 (D), Q11.6 (D), Q11.7 (D), Q11.8 (D), Q11.9 (D), R24.1, U9.3 (IN-); also elsewhere on the board
M1_OUT3: C28.1, Q12.1 (S), Q12.2 (S), Q12.3 (S), Q13.5 (D), Q13.6 (D), Q13.7 (D), Q13.8 (D), Q13.9 (D), U7.12 (VS3); also elsewhere on the board
unnamed: C26.2, D12.1 (K), U7.20 (VB1)
unnamed: C27.2, D13.1 (K), U7.17 (VB2)
unnamed: C28.2, D14.1 (K), U7.14 (VB3)
unnamed: D15.1 (A), Q8.4 (G), R25.1
unnamed: D16.1 (A), Q9.4 (G), R26.1
unnamed: D17.1 (A), Q10.4 (G), R27.1
unnamed: D18.1 (A), Q11.4 (G), R28.1
unnamed: D19.1 (A), Q12.4 (G), R29.1
unnamed: D20.1 (A), Q13.4 (G), R30.1
unnamed: C24.2, C25.2, U7.7 (VCC)
unnamed: R23.2, U8.2 (IN+)
unnamed: R24.2, U9.2 (IN+)
PGND: Q9.1 (S), Q9.2 (S), Q9.3 (S), Q11.1 (S), Q11.2 (S), Q11.3 (S), Q13.1 (S), Q13.2 (S), Q13.3 (S); also elsewhere on the board
VCC: Q8.5 (D), Q8.6 (D), Q8.7 (D), Q8.8 (D), Q8.9 (D), Q10.5 (D), Q10.6 (D), Q10.7 (D), Q10.8 (D), Q10.9 (D), Q12.5 (D), Q12.6 (D), Q12.7 (D), Q12.8 (D), Q12.9 (D); also elsewhere on the board

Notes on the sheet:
EG2133+自举
电流采样
三项全桥逆变
Motor2

Board: 2 copper layers, 130 parts (0 on the bottom side), 116 nets, no tracks yet.

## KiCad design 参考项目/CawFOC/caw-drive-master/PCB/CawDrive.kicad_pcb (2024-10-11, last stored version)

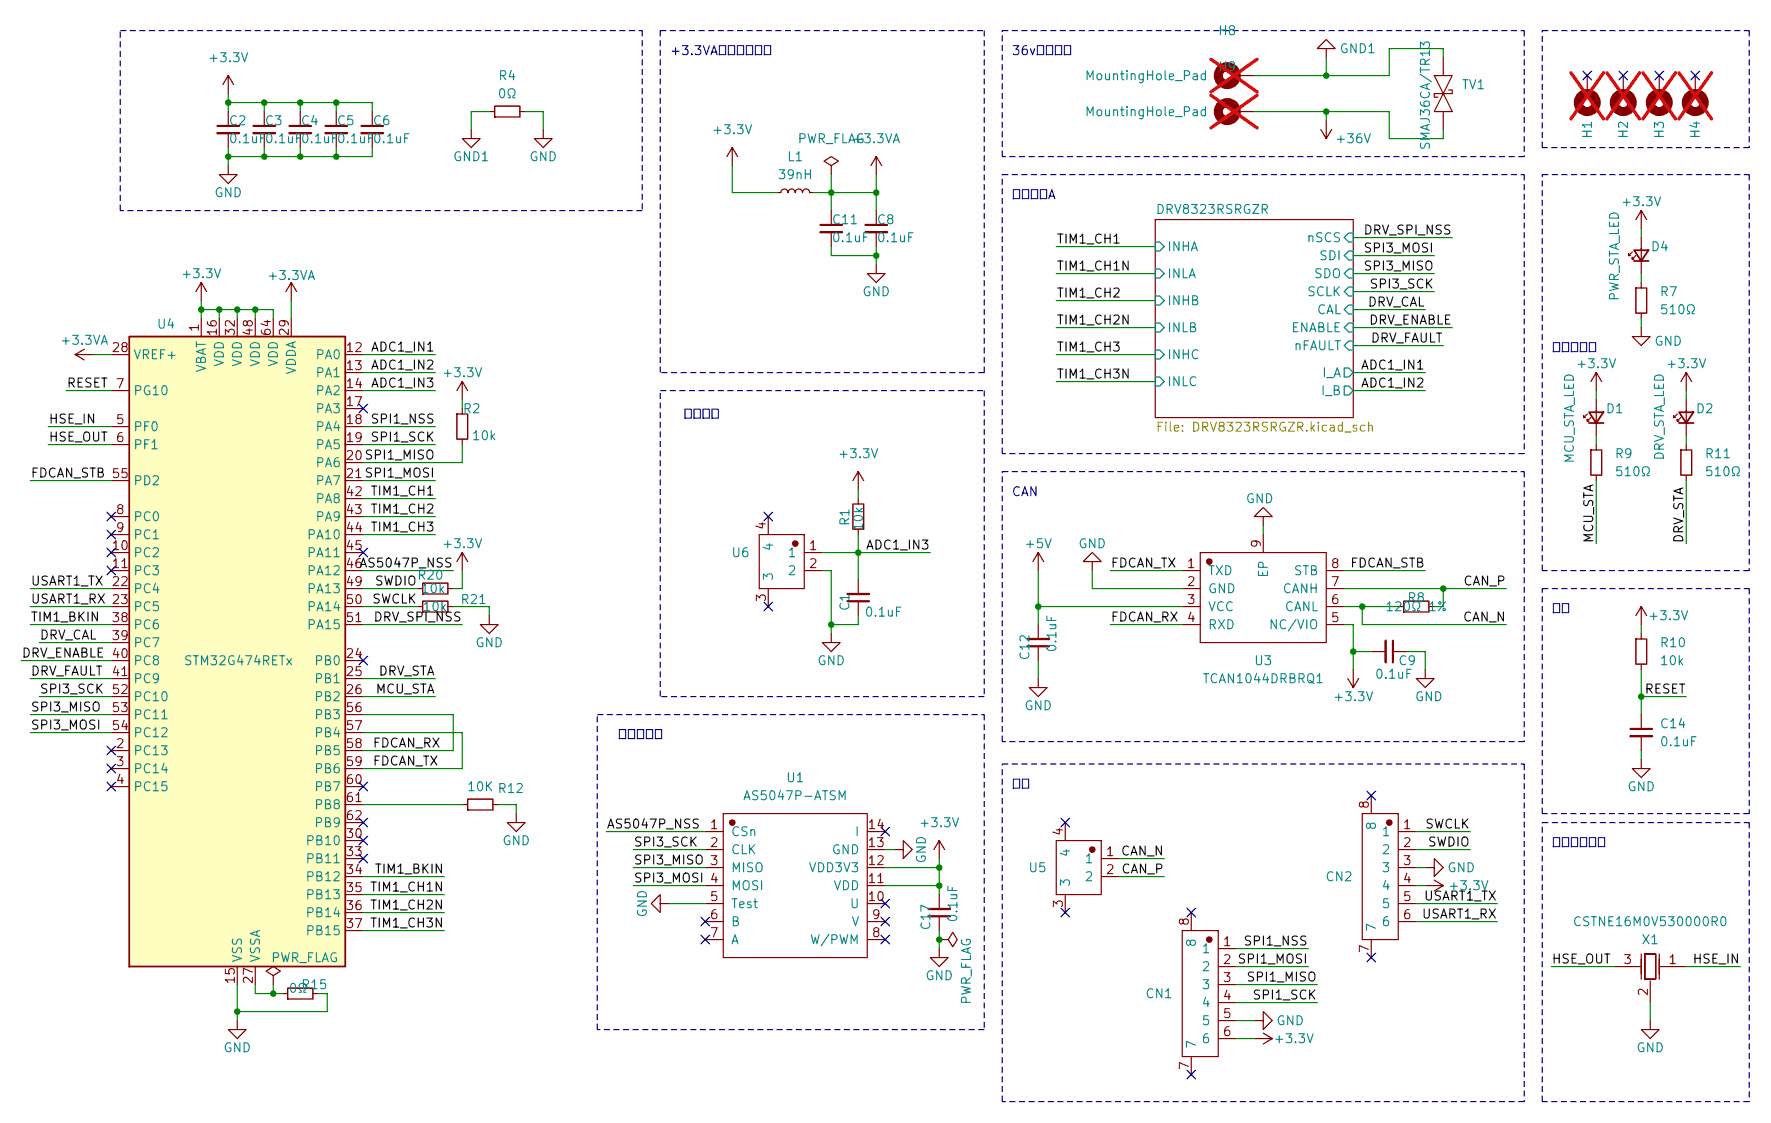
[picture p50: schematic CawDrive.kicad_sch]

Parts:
C1, C2, C3, C4, C5, C6, C8, C9, C11, C12, C14, C17: 0.1uF; C_0402_1005Metric_Pad0.74x0.62mm_HandSolder
CN1, CN2: WAFER-SH1.0-6PWB; CONN-SMD_6P-P1.00_XUNPU_WAFER-SH1.0-6PWB
D1: MCU_STA_LED; LED_0402_1005Metric_Pad0.77x0.64mm_HandSolder
D2: DRV_STA_LED; LED_0402_1005Metric_Pad0.77x0.64mm_HandSolder
D4: PWR_STA_LED; LED_0402_1005Metric_Pad0.77x0.64mm_HandSolder
H1, H2, H3, H4: MountingHole_Pad; MountingHole_2.5mm_Pad_Via; not fitted
H8, H9: MountingHole_Pad; POWER_PAD; not fitted
L1: 39nH; L_0402_1005Metric_Pad0.77x0.64mm_HandSolder
R1, R2, R10, R20, R21: 10k; R_0402_1005Metric_Pad0.72x0.64mm_HandSolder
R4, R15: 0Ω; R_0402_1005Metric_Pad0.72x0.64mm_HandSolder
R7, R9, R11: 510Ω; R_0402_1005Metric_Pad0.72x0.64mm_HandSolder
R8: 120Ω 1%; R_0402_1005Metric_Pad0.72x0.64mm_HandSolder
R12: 10K; R_0402_1005Metric_Pad0.72x0.64mm_HandSolder
TV1: SMAJ36CA/TR13; SMAJ36CA_TR13_SMA(DO-214AC); JLC Part Number C87270
U1: AS5047P-ATSM
U3: TCAN1044DRBRQ1; TCAN1044DRBRQ1_DFN-8_L3.0-W3.0-P0.65-TL-EP2.4
U4: STM32G474RETx; LQFP-64_10x10mm_P0.5mm
U5, U6: WAFER-SH1.0-2PWB; CONN-SMD_2P-P1.00_XUNPU_WAFER-SH1.0-2PWB
X1: CSTNE16M0V530000R0; Crystal_SMD3213-3P; JLC Part Number C341521

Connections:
+3.3V: C2.1, C3.1, C4.1, C5.1, C6.1, C9.2, C17.2, CN1.6, CN2.4, D1.2 (A), D2.2 (A), D4.2 (A), L1.1, R1.2, R2.1, R10.1, R20.2, U1.11 (VDD), U1.12 (VDD3V3), U3.5 (NC/VIO), U4.1 (VBAT), U4.16 (VDD), U4.32 (VDD), U4.48 (VDD), U4.64 (VDD); also elsewhere on the board
+3.3VA: C8.1, C11.1, L1.2, U4.28 (VREF+), U4.29 (VDDA)
+5V: C12.2, U3.3 (VCC); also elsewhere on the board
+36V: H9.1, TV1.1 (K); also elsewhere on the board
/ADC1_IN1: U4.12 (PA0); also elsewhere on the board
/ADC1_IN2: U4.13 (PA1); also elsewhere on the board
/ADC1_IN3: C1.2, R1.1, U4.14 (PA2), U6.1
/AS5047P_NSS: U1.1 (CSn), U4.46 (PA12)
/CAN_N: R8.1, U3.6 (CANL), U5.1
/CAN_P: R8.2, U3.7 (CANH), U5.2
/DRV_CAL: U4.39 (PC7); also elsewhere on the board
/DRV_ENABLE: U4.40 (PC8); also elsewhere on the board
/DRV_FAULT: U4.41 (PC9); also elsewhere on the board
/DRV_SPI_NSS: U4.51 (PA15); also elsewhere on the board
/DRV_STA: R11.2, U4.25 (PB1)
/FDCAN_RX: U3.4 (RXD), U4.56 (PB3), U4.58 (PB5)
/FDCAN_STB: U3.8 (STB), U4.55 (PD2)
/FDCAN_TX: U3.1 (TXD), U4.57 (PB4), U4.59 (PB6)
/HSE_IN: U4.5 (PF0), X1.1 (OSC1)
/HSE_OUT: U4.6 (PF1), X1.3 (OSC2)
/MCU_STA: R9.2, U4.26 (PB2)
/RESET: C14.1, R10.2, U4.7 (PG10)
/SPI1_MISO: CN1.3, R2.2, U4.20 (PA6)
/SPI1_MOSI: CN1.2, U4.21 (PA7)
/SPI1_NSS: CN1.1, U4.18 (PA4)
/SPI1_SCK: CN1.4, U4.19 (PA5)
/SPI3_MISO: U1.3 (MISO), U4.53 (PC11); also elsewhere on the board
/SPI3_MOSI: U1.4 (MOSI), U4.54 (PC12); also elsewhere on the board
/SPI3_SCK: U1.2 (CLK), U4.52 (PC10); also elsewhere on the board
/SWCLK: CN2.1, R21.1, U4.50 (PA14)
/SWDIO: CN2.2, R20.1, U4.49 (PA13)
/TIM1_BKIN: U4.34 (PB12), U4.38 (PC6)
/TIM1_CH1: U4.42 (PA8); also elsewhere on the board
/TIM1_CH1N: U4.35 (PB13); also elsewhere on the board
/TIM1_CH2: U4.43 (PA9); also elsewhere on the board
/TIM1_CH2N: U4.36 (PB14); also elsewhere on the board
/TIM1_CH3: U4.44 (PA10); also elsewhere on the board
/TIM1_CH3N: U4.37 (PB15); also elsewhere on the board
/USART1_RX: CN2.6, U4.23 (PC5)
/USART1_TX: CN2.5, U4.22 (PC4)
GND: C1.1, C2.2, C3.2, C4.2, C5.2, C6.2, C8.2, C9.1, C11.2, C12.1, C14.2, C17.1, CN1.5, CN2.3, R4.2, R7.2, R12.2, R15.2, R21.2, U1.5 (Test), U1.13 (GND), U3.2 (GND), U3.9 (EP), U4.15 (VSS), U4.31 (VSS), U4.47 (VSS), U4.63 (VSS), U6.2, X1.2 (GND); also elsewhere on the board
GND1: H8.1, R4.1, TV1.2 (A); also elsewhere on the board
unnamed: D1.1 (K), R9.1
unnamed: D2.1 (K), R11.1
unnamed: D4.1 (K), R7.1
unnamed: R12.1, U4.61 (PB8)
unnamed: R15.1, U4.27 (VSSA)

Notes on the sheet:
温度采样
36v电源输入
CAN
+3.3VA模拟电源滤波
位置传感器
电机驱动A
外部高速晶振
状态指示灯

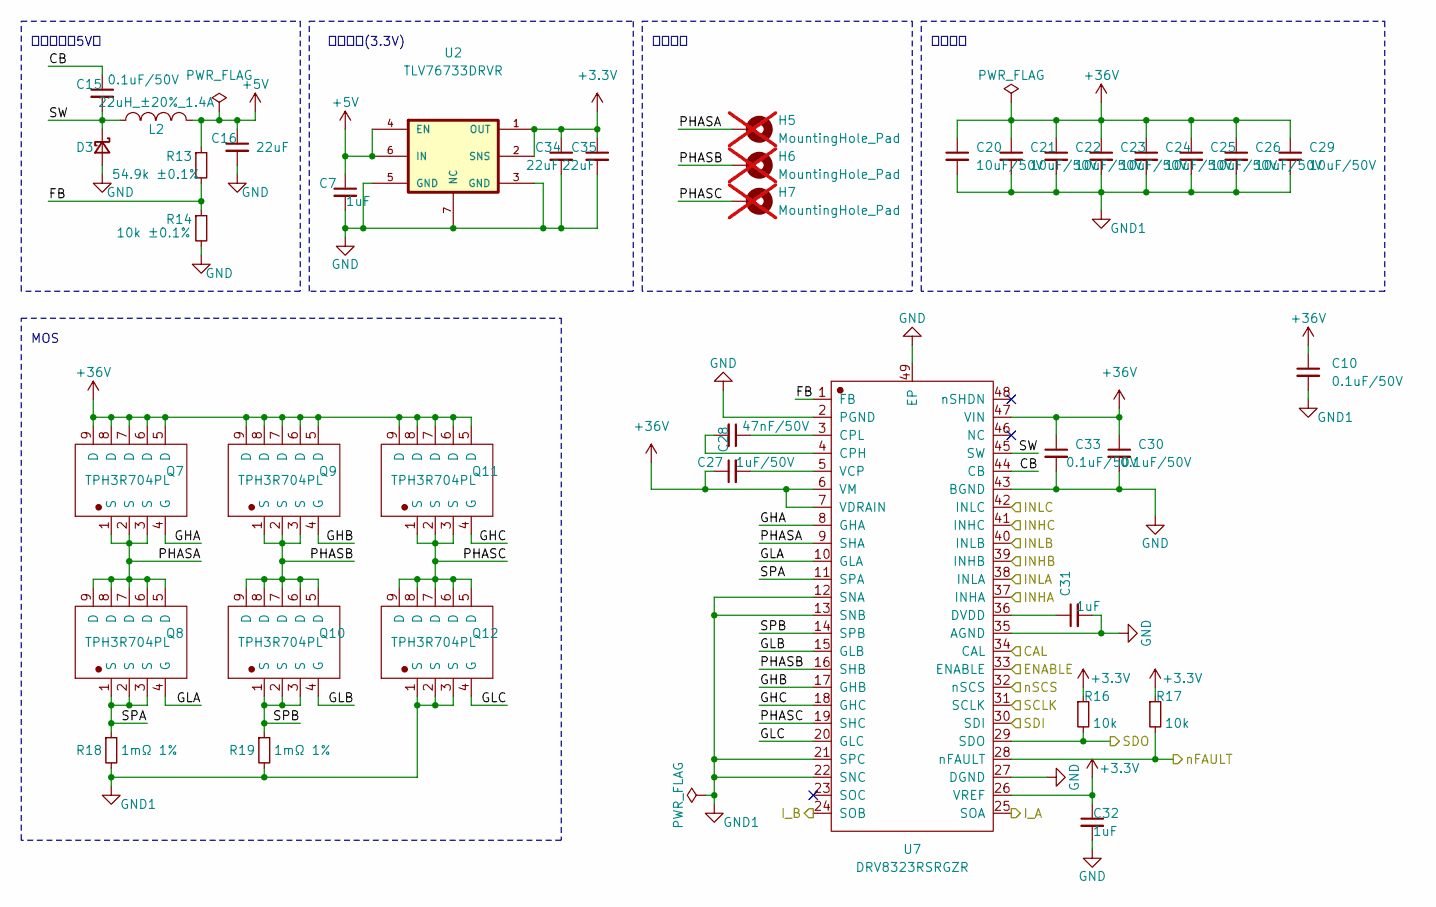
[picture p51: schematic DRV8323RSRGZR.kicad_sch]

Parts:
C7, C31, C32: 1uF; C_0402_1005Metric_Pad0.74x0.62mm_HandSolder
C10: 0.1uF/50V; C_0402_1005Metric_Pad0.74x0.62mm_HandSolder
C15, C33: 0.1uF/50V; C_0603_1608Metric_Pad1.08x0.95mm_HandSolder
C16, C34, C35: 22uF; C_0603_1608Metric_Pad1.08x0.95mm_HandSolder
C20, C21, C22, C23, C24, C25, C26, C29: 10uF/50V; C_1206_3216Metric_Pad1.33x1.80mm_HandSolder
C27: 47nF/50V; C_0402_1005Metric_Pad0.74x0.62mm_HandSolder
C28: 1uF/50V; C_0603_1608Metric_Pad1.08x0.95mm_HandSolder
C30: 0.1uF/50V; C_1206_3216Metric_Pad1.33x1.80mm_HandSolder
D3: D_Schottky_Small; D_SOD-123
H5, H6, H7: MountingHole_Pad; POWER_PAD; not fitted
L2: 22uH_±20%_1.4A; LQH5BPB220MT0L_IND-SMD_L5.0-W5.0
Q7, Q8, Q9, Q10, Q11, Q12: TPH3R704PL; TPHR8504PL,L1Q
R13: 54.9k ±0.1%; R_0402_1005Metric_Pad0.72x0.64mm_HandSolder
R14: 10k ±0.1%; R_0402_1005Metric_Pad0.72x0.64mm_HandSolder
R16, R17: 10k; R_0402_1005Metric_Pad0.72x0.64mm_HandSolder
R18, R19: 1mΩ 1%; R_1210_3225Metric_Pad1.30x2.65mm_HandSolder
U2: TLV76733DRVR; TLV76733DRVR_SON65P200X200X80-7N
U7: DRV8323RSRGZR; DRV8323RS_QFN-48-EP(7x7); JLC Part Number C545497

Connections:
+3.3V: C32.1, C34.1, C35.1, R16.1, R17.1, U2.1 (OUT), U2.2 (SNS), U7.26 (VREF); also elsewhere on the board
+5V: C7.1, C16.1, L2.2, R13.1, U2.4 (EN), U2.6 (IN); also elsewhere on the board
+36V: C10.1, C20.1, C21.1, C22.1, C23.1, C24.1, C25.1, C26.1, C28.1, C29.1, C30.1, C33.1, Q7.5 (D), Q7.6 (D), Q7.7 (D), Q7.8 (D), Q7.9 (D), Q9.5 (D), Q9.6 (D), Q9.7 (D), Q9.8 (D), Q9.9 (D), Q11.5 (D), Q11.6 (D), Q11.7 (D), Q11.8 (D), Q11.9 (D), U7.6 (VM), U7.7 (VDRAIN), U7.47 (VIN); also elsewhere on the board
/ADC1_IN1: U7.25 (SOA); also elsewhere on the board
/ADC1_IN2: U7.24 (SOB); also elsewhere on the board
/DRV8323RSRGZR/CB: C15.1, U7.44 (CB)
/DRV8323RSRGZR/FB: R13.2, R14.1, U7.1 (FB)
/DRV8323RSRGZR/GHA: Q7.4 (G), U7.8 (GHA)
/DRV8323RSRGZR/GHB: Q9.4 (G), U7.17 (GHB)
/DRV8323RSRGZR/GHC: Q11.4 (G), U7.18 (GHC)
/DRV8323RSRGZR/GLA: Q8.4 (G), U7.10 (GLA)
/DRV8323RSRGZR/GLB: Q10.4 (G), U7.15 (GLB)
/DRV8323RSRGZR/GLC: Q12.4 (G), U7.20 (GLC)
/DRV8323RSRGZR/PHASA: H5.1, Q7.1 (S), Q7.2 (S), Q7.3 (S), Q8.5 (D), Q8.6 (D), Q8.7 (D), Q8.8 (D), Q8.9 (D), U7.9 (SHA)
/DRV8323RSRGZR/PHASB: H6.1, Q9.1 (S), Q9.2 (S), Q9.3 (S), Q10.5 (D), Q10.6 (D), Q10.7 (D), Q10.8 (D), Q10.9 (D), U7.16 (SHB)
/DRV8323RSRGZR/PHASC: H7.1, Q11.1 (S), Q11.2 (S), Q11.3 (S), Q12.5 (D), Q12.6 (D), Q12.7 (D), Q12.8 (D), Q12.9 (D), U7.19 (SHC)
/DRV8323RSRGZR/SPA: Q8.1 (S), Q8.2 (S), Q8.3 (S), R18.1, U7.11 (SPA)
/DRV8323RSRGZR/SPB: Q10.1 (S), Q10.2 (S), Q10.3 (S), R19.1, U7.14 (SPB)
/DRV8323RSRGZR/SW: C15.2, D3.1 (K), L2.1, U7.45 (SW)
/DRV_CAL: U7.34 (CAL); also elsewhere on the board
/DRV_ENABLE: U7.33 (ENABLE); also elsewhere on the board
/DRV_FAULT: R17.2, U7.28 (nFAULT); also elsewhere on the board
/DRV_SPI_NSS: U7.32 (nSCS); also elsewhere on the board
/SPI3_MISO: R16.2, U7.29 (SDO); also elsewhere on the board
/SPI3_MOSI: U7.30 (SDI); also elsewhere on the board
/SPI3_SCK: U7.31 (SCLK); also elsewhere on the board
/TIM1_CH1: U7.37 (INHA); also elsewhere on the board
/TIM1_CH1N: U7.38 (INLA); also elsewhere on the board
/TIM1_CH2: U7.39 (INHB); also elsewhere on the board
/TIM1_CH2N: U7.40 (INLB); also elsewhere on the board
/TIM1_CH3: U7.41 (INHC); also elsewhere on the board
/TIM1_CH3N: U7.42 (INLC); also elsewhere on the board
GND: C7.2, C16.2, C30.2, C31.2, C32.2, C33.2, C34.2, C35.2, D3.2 (A), R14.2, U2.3 (GND), U2.5 (GND), U2.7 (NC), U7.2 (PGND), U7.27 (DGND), U7.35 (AGND), U7.43 (BGND), U7.49 (EP); also elsewhere on the board
GND1: C10.2, C20.2, C21.2, C22.2, C23.2, C24.2, C25.2, C26.2, C29.2, Q12.1 (S), Q12.2 (S), Q12.3 (S), R18.2, R19.2, U7.12 (SNA), U7.13 (SNB), U7.21 (SPC), U7.22 (SNC); also elsewhere on the board
unnamed: C27.2, U7.4 (CPH)
unnamed: C27.1, U7.3 (CPL)
unnamed: C31.1, U7.36 (DVDD)
unnamed: C28.2, U7.5 (VCP)

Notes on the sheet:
滤波电容
降压电路(3.3V)
电机接口
降压电路（5V）
MOS

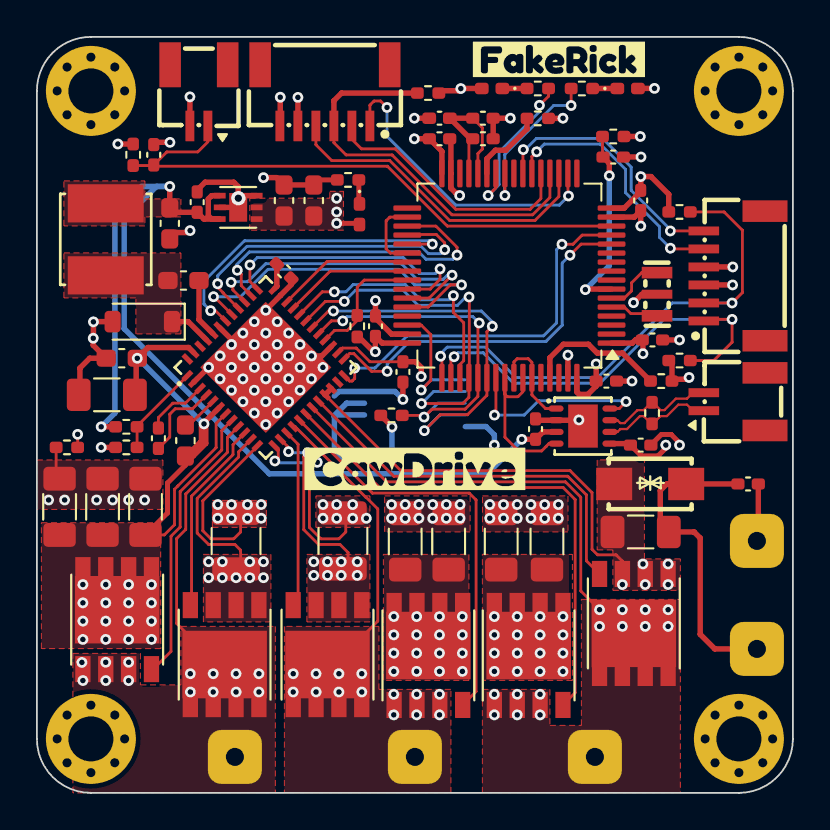
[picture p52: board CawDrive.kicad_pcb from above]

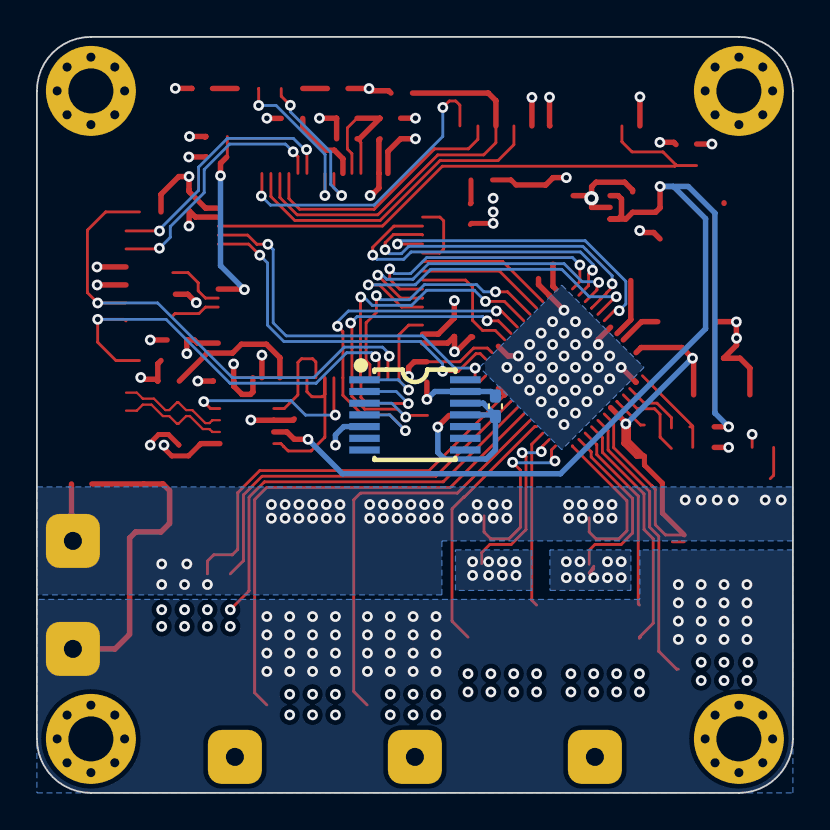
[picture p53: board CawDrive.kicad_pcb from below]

Board: 4 copper layers, 42.0 x 42.0 mm, 84 parts (2 on the bottom side), 65 nets.

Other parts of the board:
kibuzzard-66ADBF8B: G***; kibuzzard-66ADBF8B
kibuzzard-66ADCBBA: G***; kibuzzard-66ADCBBA

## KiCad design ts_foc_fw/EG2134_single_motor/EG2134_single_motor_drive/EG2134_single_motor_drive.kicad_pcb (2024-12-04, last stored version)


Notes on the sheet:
2. EG2134
1. Power
3. cirrent_sensor
目录：
4. Connection
5. Readme


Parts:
C16, C17: 100nf; C0402
R17, R18: 10k; R0402
U3, U4: TP181A1-CR

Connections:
+3V3: C16.2, C17.2, R17.2, U3.3 (V+), U4.3 (V+); also elsewhere on the board
CS1: U3.6 (OUT); also elsewhere on the board
CS2: U4.6 (OUT); also elsewhere on the board
GND: C16.1, C17.1, R18.1, U3.2 (GND), U4.2 (GND); also elsewhere on the board
IS1: U3.4 (IN+); also elsewhere on the board
IS2: U4.4 (IN+); also elsewhere on the board
PGND: U3.5 (IN-), U4.5 (IN-); also elsewhere on the board
VREF: R17.1, R18.2, U3.1 (REF), U4.1 (REF)

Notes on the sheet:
3. cirrent_sensor


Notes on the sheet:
5. Readme


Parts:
C1: 1uf; C0603
C2, C3, C4, C5: 100nf; C0603
D1, D2, D3, D4, D6, D8: 1N4148W
D5, D7, D9: DSK34
Q1, Q2, Q3, Q4, Q5, Q6: RU3089M-C
R1, R2, R5, R6, R11, R12: 20r; R0402
R3, R10: 10mr; R2512
R4: 0r; R0603
R7, R8, R9: 100r; R0402
U1: EG2134_N; EG2134-N

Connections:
GND: C1.1, C2.1, R4.2, U1.8 (GND); also elsewhere on the board
HO1: D1.1 (K), R1.1, U1.19 (HO1)
HO2: D3.1 (K), R5.1, U1.16 (HO2)
HO3: D6.1 (K), R11.1, U1.13 (HO3)
IN_1: R7.1; also elsewhere on the board
IN_2: R8.1; also elsewhere on the board
IN_3: R9.1; also elsewhere on the board
IS1: Q1.1 (S), Q1.2 (S), Q1.3 (S), R3.1; also elsewhere on the board
IS2: Q3.1 (S), Q3.2 (S), Q3.3 (S), R10.1; also elsewhere on the board
LO1: D2.1 (K), R2.1, U1.11 (LO1)
LO2: D4.1 (K), R6.1, U1.10 (LO2)
LO3: D8.1 (K), R12.1, U1.9 (LO3)
unnamed: D1.2 (A), Q2.4 (G), R1.2
unnamed: D2.2 (A), Q1.4 (G), R2.2
unnamed: D3.2 (A), Q4.4 (G), R5.2
unnamed: D4.2 (A), Q3.4 (G), R6.2
unnamed: D6.2 (A), Q6.4 (G), R11.2
unnamed: D8.2 (A), Q5.4 (G), R12.2
unnamed: R7.2, U1.1 (HIN1), U1.4 (LIN1)
unnamed: R8.2, U1.2 (HIN2), U1.5 (LIN2)
unnamed: R9.2, U1.3 (HIN3), U1.6 (LIN3)
PGND: Q5.1 (S), Q5.2 (S), Q5.3 (S), R3.2, R4.1, R10.2; also elsewhere on the board
U: C3.1, Q1.5 (D), Q1.6 (D), Q1.7 (D), Q1.8 (D), Q1.9 (D), Q2.1 (S), Q2.2 (S), Q2.3 (S), U1.18 (VS1); also elsewhere on the board
V: C4.1, Q3.5 (D), Q3.6 (D), Q3.7 (D), Q3.8 (D), Q3.9 (D), Q4.1 (S), Q4.2 (S), Q4.3 (S), U1.15 (VS2); also elsewhere on the board
VB1: C3.2, D5.1 (K), U1.20 (VB1)
VB2: C4.2, D7.1 (K), U1.17 (VB2)
VB3: C5.2, D9.1 (K), U1.14 (VB3)
VCC: C1.2, C2.2, D5.2 (A), D7.2 (A), D9.2 (A), Q2.5 (D), Q2.6 (D), Q2.7 (D), Q2.8 (D), Q2.9 (D), Q4.5 (D), Q4.6 (D), Q4.7 (D), Q4.8 (D), Q4.9 (D), Q6.5 (D), Q6.6 (D), Q6.7 (D), Q6.8 (D), Q6.9 (D), U1.7 (VCC); also elsewhere on the board
VS3: C5.1, Q5.5 (D), Q5.6 (D), Q5.7 (D), Q5.8 (D), Q5.9 (D), Q6.1 (S), Q6.2 (S), Q6.3 (S), U1.12 (VS3); also elsewhere on the board

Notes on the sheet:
2. EG2134


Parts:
CN1: XT30PW-M; XT30PW-M30.G.Y
CN2: WAFER-GH1.25-10PWB
U5: MR30PW-M30.G.Y

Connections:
CS1: CN2.7; also elsewhere on the board
CS2: CN2.6; also elsewhere on the board
GND: CN1.1 (-), CN1.3, CN1.4, CN2.1, CN2.11, CN2.12, U5.4, U5.5; also elsewhere on the board
IN_1: CN2.10; also elsewhere on the board
IN_2: CN2.9; also elsewhere on the board
IN_3: CN2.8; also elsewhere on the board
U: U5.3; also elsewhere on the board
V: U5.2; also elsewhere on the board
VCC: CN1.2 (+); also elsewhere on the board
VS3: U5.1; also elsewhere on the board

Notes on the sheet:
4. Connection


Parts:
C6, C7, C8: 22uf; C0603
C9: 100pf; C0603
C10, C13: 100nf; C0603
C11, C12, C14: 1uf; C0603
C15: 220uf; cap_pol
L1: 6.8uh; FNR6045S6R8MT
LED1: 电源指示灯; NCD0805R1
R13, R16: 10k; R0402
R14: 100k; R0603
R15: 22.1k; R0603
TP1_3V1: 3v3; TestPoint_Pad_D1.5mm
TP2_VCC1: VCC; TestPoint_Pad_D1.5mm
U2: SY8205FCC

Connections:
+3V3: C6.1, C7.1, C8.1, C9.1, L1.1, R13.2, R14.1, TP1_3V1.1; also elsewhere on the board
GND: C6.2, C7.2, C8.2, C11.2, C12.2, C13.1, C14.1, C15.2, LED1.2 (-), R15.2, U2.9 (GND); also elsewhere on the board
unnamed: LED1.1 (+), R13.1
unnamed: C10.2, U2.1 (BS)
unnamed: C10.1, L1.2, U2.2 (LX)
unnamed: C11.1, U2.4 (SS)
unnamed: C12.1, U2.6 (VCC)
VCC: C13.2, C14.2, C15.1, R16.1, TP2_VCC1.1, U2.7 (VIN), U2.8 (VIN); also elsewhere on the board
power_en: R16.2, U2.3 (EN)
power_fb: C9.2, R14.2, R15.1, U2.5 (FB)

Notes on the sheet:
1. Power



Board: 4 copper layers, 61.3 x 22.9 mm, 61 parts (35 on the bottom side), 40 nets.

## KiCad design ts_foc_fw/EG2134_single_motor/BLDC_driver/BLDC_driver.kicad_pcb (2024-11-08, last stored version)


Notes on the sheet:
DC-DC 12/24 -> 5V
EG2134驱动
Cirrent_sensor
readme:
目录：
Connection


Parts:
CN1: XT30PW-M; XT30PW-M30.G.Y
CN2: MR30PW-M30.G.Y
CN3: WAFER-GH1.25-10PWB

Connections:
+12V: CN1.2 (+); also elsewhere on the board
GND: CN1.1 (-), CN1.3, CN1.4, CN2.4, CN2.5, CN3.1, CN3.2, CN3.3, CN3.4, CN3.5, CN3.11, CN3.12; also elsewhere on the board
M0_IN1: CN3.8; also elsewhere on the board
M0_IN2: CN3.7; also elsewhere on the board
M0_IN3: CN3.6; also elsewhere on the board
M0_OUT1_CS: CN3.10; also elsewhere on the board
M0_OUT1_N: CN2.3; also elsewhere on the board
M0_OUT2_CS: CN3.9; also elsewhere on the board
M0_OUT2_N: CN2.2; also elsewhere on the board
M0_OUT3: CN2.1; also elsewhere on the board

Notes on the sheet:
Connection


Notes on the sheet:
1. 原理图:50mil 2. PCB :10mil
栅格尺寸：

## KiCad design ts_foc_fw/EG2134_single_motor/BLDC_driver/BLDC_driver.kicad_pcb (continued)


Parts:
C10: 1uf; C0603
C11, C12, C13, C14: 100nf; C0603
C15, C16, C17, C18: 10uf; C0805
D2, D3, D4: 1N5819WS
Q1, Q2, Q3, Q4, Q5, Q6: RU3089M-C
R6, R8, R11, R13, R15, R17: 2.2; R0402
R7, R9, R10, R12, R14, R16: 10k; R0402
R20: 0; R0805
U1: EG2134_N; EG2134

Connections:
+5V: D2.2 (A), D3.2 (A), D4.2 (A); also elsewhere on the board
+12V: C15.1, C16.1, C17.1, C18.1, Q1.5 (D), Q1.6 (D), Q1.7 (D), Q1.8 (D), Q1.9 (D), Q3.5 (D), Q3.6 (D), Q3.7 (D), Q3.8 (D), Q3.9 (D), Q5.5 (D), Q5.6 (D), Q5.7 (D), Q5.8 (D), Q5.9 (D); also elsewhere on the board
GND: C10.1, C11.1, R20.1, U1.8 (GND); also elsewhere on the board
M0_GH1: R6.2, U1.19 (HO1)
M0_GH2: R13.2, U1.16 (HO2)
M0_GH3: R17.2, U1.13 (HO3)
M0_GL1: R8.1, U1.11 (LO1)
M0_GL2: R11.1, U1.10 (LO2)
M0_GL3: R15.1, U1.9 (LO3)
M0_IN1: U1.1 (HIN1), U1.4 (LIN1); also elsewhere on the board
M0_IN2: U1.2 (HIN2), U1.5 (LIN2); also elsewhere on the board
M0_IN3: U1.3 (HIN3), U1.6 (LIN3); also elsewhere on the board
M0_OUT1_P: C12.1, Q1.1 (S), Q1.2 (S), Q1.3 (S), Q2.5 (D), Q2.6 (D), Q2.7 (D), Q2.8 (D), Q2.9 (D), R7.1, U1.18 (VS1); also elsewhere on the board
M0_OUT2_P: C13.1, Q3.1 (S), Q3.2 (S), Q3.3 (S), Q4.5 (D), Q4.6 (D), Q4.7 (D), Q4.8 (D), Q4.9 (D), R12.1, U1.15 (VS2); also elsewhere on the board
M0_OUT3: C14.1, Q5.1 (S), Q5.2 (S), Q5.3 (S), Q6.5 (D), Q6.6 (D), Q6.7 (D), Q6.8 (D), Q6.9 (D), R16.1, U1.12 (VS3); also elsewhere on the board
unnamed: C12.2, D2.1 (K), U1.20 (VB1)
unnamed: C13.2, D3.1 (K), U1.17 (VB2)
unnamed: C14.2, D4.1 (K), U1.14 (VB3)
unnamed: Q1.4 (G), R6.1, R7.2
unnamed: Q2.4 (G), R8.2, R9.1
unnamed: Q3.4 (G), R12.2, R13.1
unnamed: Q4.4 (G), R10.1, R11.2
unnamed: Q5.4 (G), R16.2, R17.1
unnamed: Q6.4 (G), R14.1, R15.2
unnamed: C10.2, C11.2, U1.7 (VCC)
PGND: C15.2, C16.2, C17.2, C18.2, Q2.1 (S), Q2.2 (S), Q2.3 (S), Q4.1 (S), Q4.2 (S), Q4.3 (S), Q6.1 (S), Q6.2 (S), Q6.3 (S), R9.2, R10.2, R14.2, R20.2

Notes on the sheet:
EG2134驱动


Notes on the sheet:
MCU


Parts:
R18, R19: 10mr; R2512
U3, U4: INA240A2PW

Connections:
+3.3V: U3.5 (VS), U3.6 (REF2), U4.5 (VS), U4.6 (REF2); also elsewhere on the board
GND: U3.4 (GND), U3.7 (REF1), U4.4 (GND), U4.7 (REF1); also elsewhere on the board
M0_OUT1_CS: U3.8 (OUT); also elsewhere on the board
M0_OUT1_N: R18.2, U3.2 (IN+); also elsewhere on the board
M0_OUT1_P: R18.1, U3.3 (IN-); also elsewhere on the board
M0_OUT2_CS: U4.8 (OUT); also elsewhere on the board
M0_OUT2_N: R19.2, U4.2 (IN+); also elsewhere on the board
M0_OUT2_P: R19.1, U4.3 (IN-); also elsewhere on the board

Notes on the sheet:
Connection


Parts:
C1, C2, C19, C22: 4.7uf; C0805
C3, C20, C21: 100nf; C0603
C4: 8.2nf; C0603
C5: 1.2nf; C0603
C6: 10pf; C0603
C7: 100nf; C0805
C8, C9: 10uf; C0805
D1: SS34; ss34
L1: SWPA5040S6R8M; SWPA5040S6R8MT
R1: 10k; R0603
R2: 330k; R0603
R3: 68k; R0603
R4: 30k; R0603
R5: 1.87k; R0603
U2: TPS54331DDAR; tps54331
U5: AMS1117-3.3(SOT-89); AMS11173v3-SOT-89

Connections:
+3.3V: C21.2, C22.2, U5.2 (Vout); also elsewhere on the board
+5V: C8.2, C9.2, C19.2, C20.2, L1.2, R1.2, U5.3 (Vin); also elsewhere on the board
+12V: C1.2, C2.2, C3.2, R2.2, U2.2 (VIN); also elsewhere on the board
GND: C1.1, C2.1, C3.1, C4.1, C6.1, C8.1, C9.1, C19.1, C20.1, C21.1, C22.1, D1.2 (A), R3.1, R4.1, R5.1, U2.7 (GND), U2.9 (EP), U5.1 (GND); also elsewhere on the board
unnamed: C5.1, R4.2
unnamed: C7.1, D1.1 (K), L1.1, U2.8 (PH)
unnamed: C7.2, U2.1 (BOOT)
unnamed: C5.2, C6.2, U2.6 (COMP)
unnamed: R2.1, R3.2, U2.3 (EN)
unnamed: C4.2, U2.4 (SS)
unnamed: R1.1, R5.2, U2.5 (VSENSE)

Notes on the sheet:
DC-DC 12/24 -> 5V
Power



Board: 2 copper layers, 68.9 x 31.5 mm, 61 parts (15 on the bottom side), 38 nets.

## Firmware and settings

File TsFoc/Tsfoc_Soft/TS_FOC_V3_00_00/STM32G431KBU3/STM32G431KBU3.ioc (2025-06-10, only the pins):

Mcu.UserName=STM32G431KBUx
PA0.Signal=ADC1_IN1
PA1.Signal=ADC1_IN2
PA10.Signal=S_TIM1_CH3
PA11.Signal=FDCAN1_RX
PA12.Signal=FDCAN1_TX
PA13.Signal=SYS_JTMS-SWDIO
PA14.Signal=SYS_JTCK-SWCLK
PA15.Signal=I2C1_SCL
PA2.GPIO_Label=RGB_R
PA2.Signal=S_TIM2_CH3
PA3.GPIO_Label=RGB_G
PA3.Signal=S_TIM2_CH4
PA4.GPIO_Label=LED2
PA4.Signal=GPIO_Output
PA5.Signal=SPI1_SCK
PA6.Signal=SPI1_MISO
PA7.Signal=TIM1_CH1N
PA8.Signal=S_TIM1_CH1
PA9.Signal=S_TIM1_CH2
PB0.Signal=TIM1_CH2N
PB3.Signal=USART2_TX
PB4.Signal=USART2_RX
PB5.Signal=SPI1_MOSI
PB6.GPIO_Label=RGB_B
PB6.Signal=S_TIM8_CH1
PB7.Signal=I2C1_SDA
PB8-BOOT0.GPIO_Label=BOOT0
PB8-BOOT0.Signal=GPIO_Input
PF0-OSC_IN.Signal=TIM1_CH3N
PF1-OSC_OUT.GPIO_Label=LED1
PF1-OSC_OUT.Signal=GPIO_Output
PG10-NRST.Signal=GPIO_Input

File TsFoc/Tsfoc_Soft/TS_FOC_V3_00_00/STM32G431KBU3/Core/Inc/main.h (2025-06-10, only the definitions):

#define LED1_Pin GPIO_PIN_1
#define LED1_GPIO_Port GPIOF
#define RGB_R_Pin GPIO_PIN_2
#define RGB_R_GPIO_Port GPIOA
#define RGB_G_Pin GPIO_PIN_3
#define RGB_G_GPIO_Port GPIOA
#define LED2_Pin GPIO_PIN_4
#define LED2_GPIO_Port GPIOA
#define RGB_B_Pin GPIO_PIN_6
#define RGB_B_GPIO_Port GPIOB
#define BOOT0_Pin GPIO_PIN_8
#define BOOT0_GPIO_Port GPIOB

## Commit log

2024-10-03 第一次同步_FOC算法已经验证并且移植到STM32使用HAL库
2024-10-03 更新readme
2024-10-10 增加本杰明项目源码和cawfoc开发板资料
2024-10-11 永磁双驱
    [CawDrive-B_Cu.gbr, CawDrive-B_Mask.gbr, CawDrive-B_Paste.gbr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]
2024-10-16 增加odriver硬件资料
2024-10-20 初始化0_2版本，需要判断是否是角度传感器获取角度太慢了导致速度上来以后旋转变得卡顿，待验证
2024-10-22 同步问题
2024-10-23 规整文件分类
2024-10-31 增加eg2133和eg2134芯片对比文档
2024-11-06 记录编码器硬件问题
2024-11-07 增加kicad硬件版本基于eg2134栅极驱动芯片单个电机电调
    [BLDC_driver.kicad_pcb, BLDC_driver.kicad_sch, Connection.kicad_sch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]
2024-11-07 add the cap c0603
    [BLDC_driver.kicad_pcb, Power.kicad_sch]
2024-11-07 原理图移植完成,PCB还没有布局
    [BLDC_driver.kicad_pcb, BLDC_driver.kicad_sch, Connection.kicad_sch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]
2024-11-08 同步20241108_night
    [BLDC_driver.kicad_pcb, Connection.kicad_sch, Power.kicad_sch]
2024-11-09 迭代版本,初版原理图移植有问题,不可使用
    [BLDC_driver.kicad_pcb, BLDC_driver.kicad_sch, Connection.kicad_sch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]
2024-11-09 第二版基于EG2134嘉立创开元项目原理图完成
    [Connection.kicad_sch, EG2134.kicad_sch, EG2134_single_motor_drive.kicad_pcb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]
2024-11-13 PCB布局完成，等待布线
    [Connection.kicad_sch, EG2134.kicad_sch, EG2134_single_motor_drive.kicad_pcb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]
2024-11-14 第一版走线完成,准备打板子验证
    [EG2134_single_motor_drive.kicad_pcb]
2024-12-08 2024-12-8同步数据
2024-12-08 重新生成代码前的备份
2024-12-17 F411电压力矩位置环调试完成
2024-12-17 使用串口命令驱动位置闭环和力矩闭环
2024-12-23 同步_2024年 12月 23日 星期一 16:47:35 CST
2024-12-23 同步_2024年 12月 23日 星期一 16:48:38 CST
2024-12-23 同步_2024年 12月 23日 星期一 16:51:04 CST
2024-12-26 同步_2024年 12月 26日 星期四 12:47:49 CST
2025-01-04 同步_2025年 01月 04日 星期六 19:33:09 CST
    [10M08SAREVERSIONTEST_Library.SchLib, Analouge.SchDoc, AuxHalfH.SchDoc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]
2025-01-04 同步_2025年 01月 04日 星期六 19:34:21 CST
2025-01-04 同步_2025年 01月 04日 星期六 19:38:04 CST
    [10M08SAREVERSIONTEST_Library.SchLib, Analouge.SchDoc, AuxHalfH.SchDoc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]
2025-01-08 同步_2025年 01月 08日 星期三 20:50:40 CST
    [EG2133_MOTOR_DRIVE_SINGLE_V2_0.kicad_pcb, EG2133_MOTOR_DRIVE_SINGLE_V2_0.kicad_sch]
2025-01-08 同步_2025年 01月 08日 星期三 20:53:07 CST
    [CawDrive-B_Cu.gbr, CawDrive-B_Mask.gbr, CawDrive-B_Paste.gbr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]
2025-01-10 同步_2025年 01月 10日 星期五 17:15:53 CST
2025-01-10 同步_2025年 01月 10日 星期五 17:37:28 CST
    [EG2133_MOTOR_DRIVE_SINGLE_V2_0.kicad_pcb, EG2133_MOTOR_DRIVE_SINGLE_V2_0.kicad_sch]
2025-01-12 同步_2025年 01月 13日 星期一 03:33:41 CST
2025-01-12 同步_2025年 01月 13日 星期一 03:36:46 CST
2025-01-12 更新gitpush脚本_2025年 01月 13日 星期一 03:39:53 CST
2025-01-12 同步_2025年 01月 13日 星期一 03:43:02 CST
2025-01-12 同步_2025年 01月 13日 星期一 03:48:27 CST
2025-01-12 同步_2025年 01月 13日 星期一 03:50:56 CST
2025-01-22 同步_2025年 01月 22日 星期三 19:18:24 CST
2025-01-23 同步_Thu Jan 23 21:05:17 2025
    [Ts_Foc_Vo1_0.kicad_pcb, Ts_Foc_Vo1_0.kicad_sch]
2025-01-24 同步_Fri Jan 24 20:31:29 2025
    [12-5V.kicad_sch, 5-3V3.kicad_sch, CAN.kicad_sch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]
2025-01-24 重新整理目录分类分组
    [12-5V.kicad_sch, 5-3V3.kicad_sch, CAN.kicad_sch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]
2025-01-27 vscode尝试同步
    [Connector.kicad_sch, Ts_Foc_Vo1_0.kicad_pcb]
2025-01-31 同步_原理图小幅优化
    [12-5V.kicad_sch, 5-3V3.kicad_sch, Mcu.kicad_sch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]
2025-01-31 添加第二批器材采购清单
2025-02-03 添加esc布局板子,备份分离封装库以及符号库,添加主线封装符号库
    [12-5V.kicad_sch, 5-3V3.kicad_sch, CAN.kicad_sch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]
2025-02-03 电源走线完成
    [Power.kicad_sch, STM32F407VET6.kicad_sch, Ts_Foc_Vo1_0.kicad_pcb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]
2025-02-04 第一版layout完成，准备打板验证
    [CAN.kicad_sch, Connector.kicad_sch, Ts_Foc_Vo1_0.kicad_pcb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]
2025-02-04 同步_Tue Feb 4 22:38:42 2025
    [12-5V.kicad_sch, 5-3V3.kicad_sch, Connector.kicad_sch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]
2025-02-13 同步_Thu Feb 13 10:52:48 2025
2025-02-14 同步_Fri Feb 14 17:11:07 2025
2025-03-26 创建f407程序项目
2025-03-28 cmd线程整理完毕
    [Ts_Foc_Vo1_0.kicad_pcb]
2025-03-28 同步_Fri Mar 28 13:18:06 2025
2025-04-11 同步_Fri Apr 11 16:16:38 2025
2025-04-14 同步_Mon Apr 14 13:56:21 2025
    [12-5V.kicad_sch, 5-3V3.kicad_sch, CAN.kicad_sch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]
2025-04-15 同步_Tue Apr 15 15:07:48 2025
2025-04-15 同步_Tue Apr 15 15:08:52 2025
2025-05-01 导入F411TSFOC代码
    [12-5V.kicad_sch, 5-3V3.kicad_sch, CAN.kicad_sch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]
2025-05-02 移植了get_cmd线程，但是接收不到数据。
2025-05-02 修复get_cmd接收问题
2025-05-03 1. can通信测试通过 2. as5600通信测试通过 3. PCB板桥驱动电路有标签错误，导致有四个引脚未能链接 4.
    [Ts_Foc_Vo1_0.kicad_pcb, drive1.kicad_sch, drive2.kicad_sch]
2025-05-05 嘉立创tsfocvesc201设计完成
    [12-5V.kicad_sch, 5-3V3.kicad_sch, CAN.kicad_sch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]
2025-05-05 添加oled支持
2025-05-05 1. 整理了所有代码 2. 优化了代码目录 3. 将所有的任务分开了
2025-05-09 同步文件到main分支
    [12-5V.kicad_sch, 5-3V3.kicad_sch, CAN.kicad_sch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]
2025-05-11 添加tsfoc库 1. 实现简易电压位置闭环控制 2. 实现简易电压力矩闭环控制
    [5-3V3.kicad_sch]
2025-05-14 同步_Wed May 14 10:58:01 2025
2025-06-03 同步代码
2025-06-04 汇总论文相关文件
2025-06-07 添加电流采样方案

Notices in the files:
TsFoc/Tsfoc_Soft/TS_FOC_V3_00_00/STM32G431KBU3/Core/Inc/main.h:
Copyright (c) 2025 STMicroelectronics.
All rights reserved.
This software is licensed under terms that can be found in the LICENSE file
